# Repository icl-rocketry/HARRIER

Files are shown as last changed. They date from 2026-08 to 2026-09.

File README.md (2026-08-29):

# Project HARRIER

Solid-state particle detector for a rocket payload. Detects cosmic radiation
throughout flight and logs each hit with altitude, to build up counting
statistics post-flight.

Built in KiCad. Mixed-signal board: the detector board reads two independent
silicon-diode detector channels and logs events. 

## How it works 

A cosmic particle hits a reverse-biased photodiode and dumps a few femtocoulombs
of charge. A charge-sensitive amplifier turns that into a ~7 mV pulse, a
comparator checks it against a tunable threshold and the output signal is processed
by a seperate Pickle Rick board.

## Repository layout

The KiCad project has five schematic sheets:
Using the ICLR Board Template

| Sheet | Contents |
|---|---|
| Root | status LEDs, connectors, test points |
| Power Board | Three isolated rails off a ~7.4V battery: +25V bias, +5V analogue, +3.3V digital |
| Detector Board | The signal chain: diodes, charge amps, comparators (2 channels) |

## specs

- **Enclosure:** Circa 90 x 90 x 100 mm (TBD), light-tight detector housing
- **Power:** ~1.5 W from a ~7.4V battery (cell TBC)
- **Detector:** 2x BPW34 photodiodes, biased at +50V
- **Front-end:** ADA4817-1 charge amp, TLV3201 comparator, per channel
- **MCU:** ESP32-S3

## Status

Work in progress. Schematic of the detector front-end is nearly
complete; layout, bring-up, and firmware still to come.

**Outstanding before layout:**
- Confirm comparator edge polarity on the bench (rising vs falling) before
  writing interrupt firmware
- Clear all ERC

## Firmware

Firmware is set up for PlatformIO. Clone the repo and open in PlatformIO to
build and flash.

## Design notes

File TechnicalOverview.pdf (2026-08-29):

## HARRIER – High Altitude Radiation Rate Ionisation Experiment Recorder

HARRIER is an experiment that is part of the New Horizons’ Payload for launch at EUROC 2026. It is a photodiode-based radiation detector that aims to measure the change in radiation rate at different altitudes. We expect the rate to increase with altitude as cosmic rays are less attenuated by the atmosphere at higher altitudes.
It consists of 2 separate boards; a detector board that contains the photodiode and outputs a digital signal and a power board that provides 25V and 5V voltages, as well as containing the on/off switch. They are stored along with their own separate battery in a 5mm thick casing that blocks alpha radiation.

## The experiment

HARRIER outputs a ‘high’ signal when a particle is detected. By monitoring the output channel, we store the timestamps where detection events occurred. This can allow us to synchronise the events with altitude readings on the Pickle-Rick’s altimeter, producing a list of events and the altitudes they occur

## The detector

A photodiode is utilised to detect incoming radiation. When particles collide with the silicon surface of the diode, ionisation of donor atoms can occur, which results in additional free electrons being increased. This manifests as a small introduction of charge (on order of several femtocoulombs) and therefore current across the diode. To increase the sensitivity of the photodiode, a 25V reverse bias is applied this photodiode. Then we convert this change in charge to a voltage output signal using a charge-sensitive preamplifier (CSP), which produces an output proportional to the integrated charge over its sampling time. This means small fluctuations in current can be detected once converted into a voltage output. During detection events, a voltage of ~7mV is expected to be produced. The CSP requires a 5V input.
This output is then fed into a comparator which will output a ‘high’ signal (5V) if a voltage threshold is exceeded during its sampling window. We set the voltage threshold with a voltage divider with a variable resistor. Otherwise, a ‘low’ signal of about 0V is outputted. We use this as an approximation of counts per second by counting how many times a high signal is outputted.
A voltage divider is used to reduce comparator output to 3.3V so it can be directly connected to a GPIO pin on the Pickle-Rick board, which will store the count rate data on an SD card.

Inputs required:

- +25V power rail for photodiode
- +5V power rail for comparator and CSP Outputs:
- +3.3V digital output

Design considerations
We can also distinguish cosmic rays from EM radiation by their energy levels. Massive particles generally have far higher energies than photons from EM radiation. Therefore, by setting the threshold on the comparator above a certain level we can ignore low energy counts.
An issue with the detection of cosmic rays is that they are very fast (near light speed) so will not stay long inside the photodiode. By applying a 25V reverse bias voltage we can greatly increase the response time and sensitivity, allowing detection of these fast particles.

## Power board

The secondary board simply provides power for the main detector board. We must transform the battery power input into the correct voltages for the detector, which are 5V for the comparator and 25V for the amplifier.
The 25V input is provided by a buck boost from 7.4V to 27.5V, followed by an LDO regulator that reduces the voltage to 25V. This ensures a stable output signal as battery voltage is not consistent. For the 5V rail, we use another regulator to reduce the 7.4V input to 5V.
To turn the detector on/off, a MOSFET switch is used to switch the boost and 5V LDO on and off by disconnecting them from the battery input. This takes a 3.3V GPIO input from either the Flint and Steel board or the main Pickle Rick board. In turn, this deactivates the detector board. The power board should activate when the rest of the payload module turns on.
Inputs:
- ~7.4V battery input
- ~ 3.3V digital on/off input Outputs:

- +25V rail
- +5V rail

Design considerations:
We decided to separate the detector board from the power board for 2 main reasons.
1. Horizontal spacing requirements in the payload module- the detector should roughly point upwards for the highest count rate of cosmic radiation, but this would make a combined board to wide to fit into the casing. By separating the boards, we can mount the detector horizontally and the power board vertically, ensuring we had enough space.
2. Testing and reliability - we could independently test the detector board and if necessary, replace it if it was not working or malfunctioned. This reduces the risks of failure as if either board fails, it can be replaced separately.

## Casing

The Harrier module is designed to be self-contained. It is connected to the Pickle Rick with the data output from the comparator and the on/off switch labels. It has its own separate battery within its case. We use a separate battery to ensure that power draw is more stable, so the input voltage and current is more consistent.
The casing consists of two 3D printed parts that slot together to form a closed box. Raised screws are used to hold the boards in place.
A key issue with photodiode detectors is that electromagnetic radiation will also be detected by the diode. We can avoid this by using a casing that blocks visible light from falling on the diode. Microwaves and radio waves may penetrate the casing, but they have far lower photon energies so are unlikely to cause any ionisation.

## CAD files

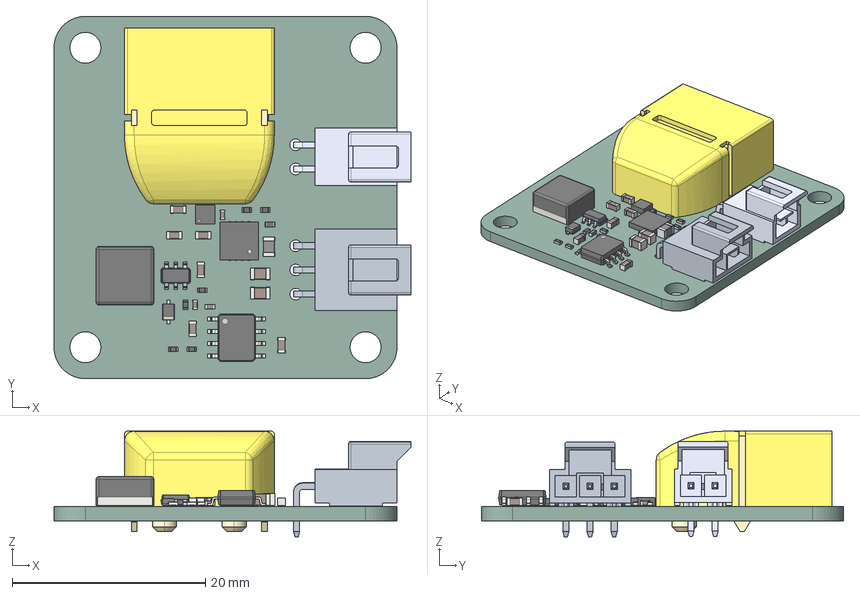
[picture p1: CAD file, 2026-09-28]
raven-main/Detector-Power-Board/power-board.step
36.9 x 37.5 x 10.9 mm
C_0603_1608Metric x 6
C_0402_1005Metric x 3
R_0402_1005Metric x 7
WSON_6_1EP_2x2mm_P065mm_EP1x16mm
Texas_RSA_VQFN-16-1EP_4x4mm_P0.65mm_EP2.7x2.7mm
XT60PW MALE
C_0805_2012Metric x 2
SOIC-8-1EP_3.9x4.9mm_P1.27mm_EP2.41x3.81mm
L_Cenker_CKCS6028
L_0805_2012Metric
D_SOD_323F
TSOP-6_1.65x3.05mm_P0.95mm
detector-power_PCB

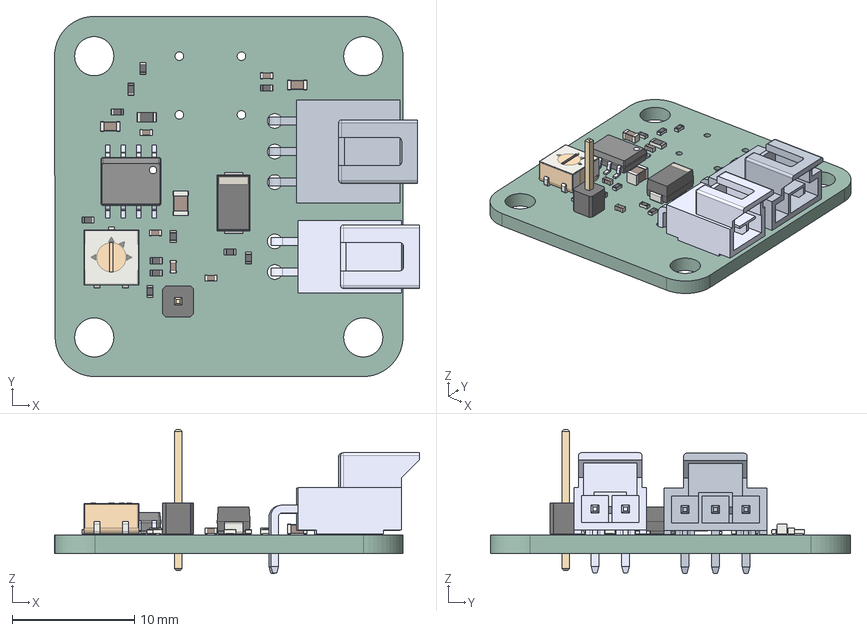
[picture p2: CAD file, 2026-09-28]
raven-main/Detector-Proto-Board/Detector-Proto-Board.step
29.9 x 29.5 x 11.8 mm
R_0402_1005Metric x 11
STS8DN3LLH5
C_0402_1005Metric x 5
Potentiometer_Bourns_3314J_Vertical
PinHeader_1x01_P254mm_Vertical
C_0603_1608Metric x 2
R_0603_1608Metric
C_0805_2012Metric
D_SMA
Detector-Proto-Board-unsaved-export-pvpNuH_PCB

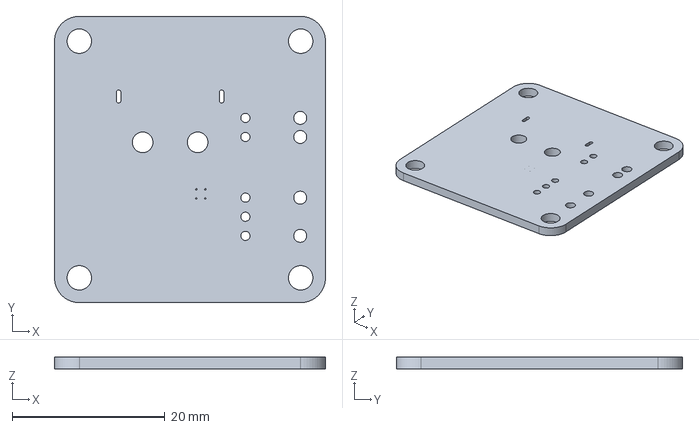
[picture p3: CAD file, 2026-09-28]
raven-main/Detector-Power-Board/test-board2.step
35.5 x 37.5 x 1.51 mm

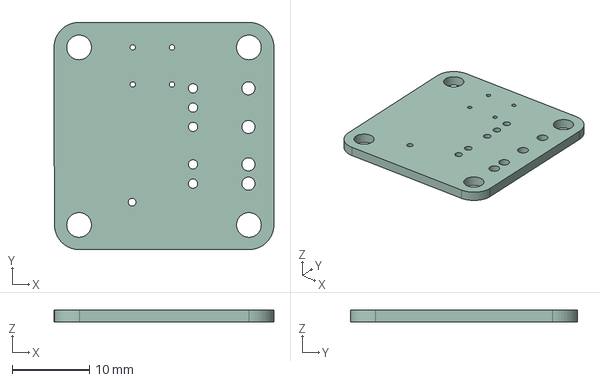
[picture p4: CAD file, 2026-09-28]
raven-main/Detector-Proto-Board/test-board.step
28.5 x 29.5 x 1.51 mm

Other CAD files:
raven-main/Detector-Proto-Board/proto-board.step

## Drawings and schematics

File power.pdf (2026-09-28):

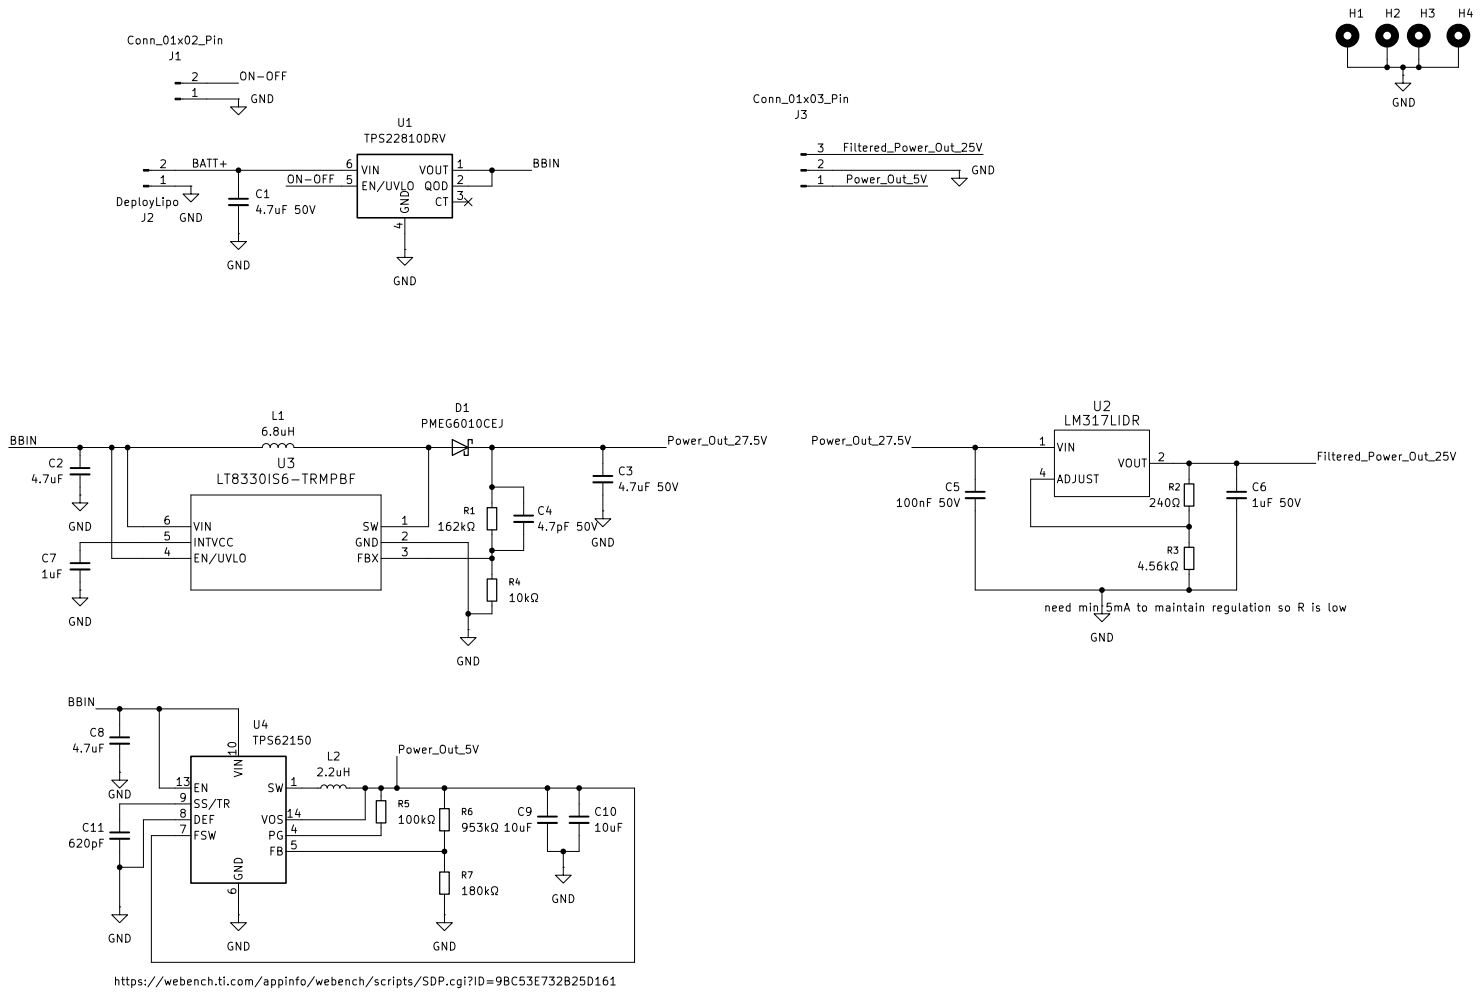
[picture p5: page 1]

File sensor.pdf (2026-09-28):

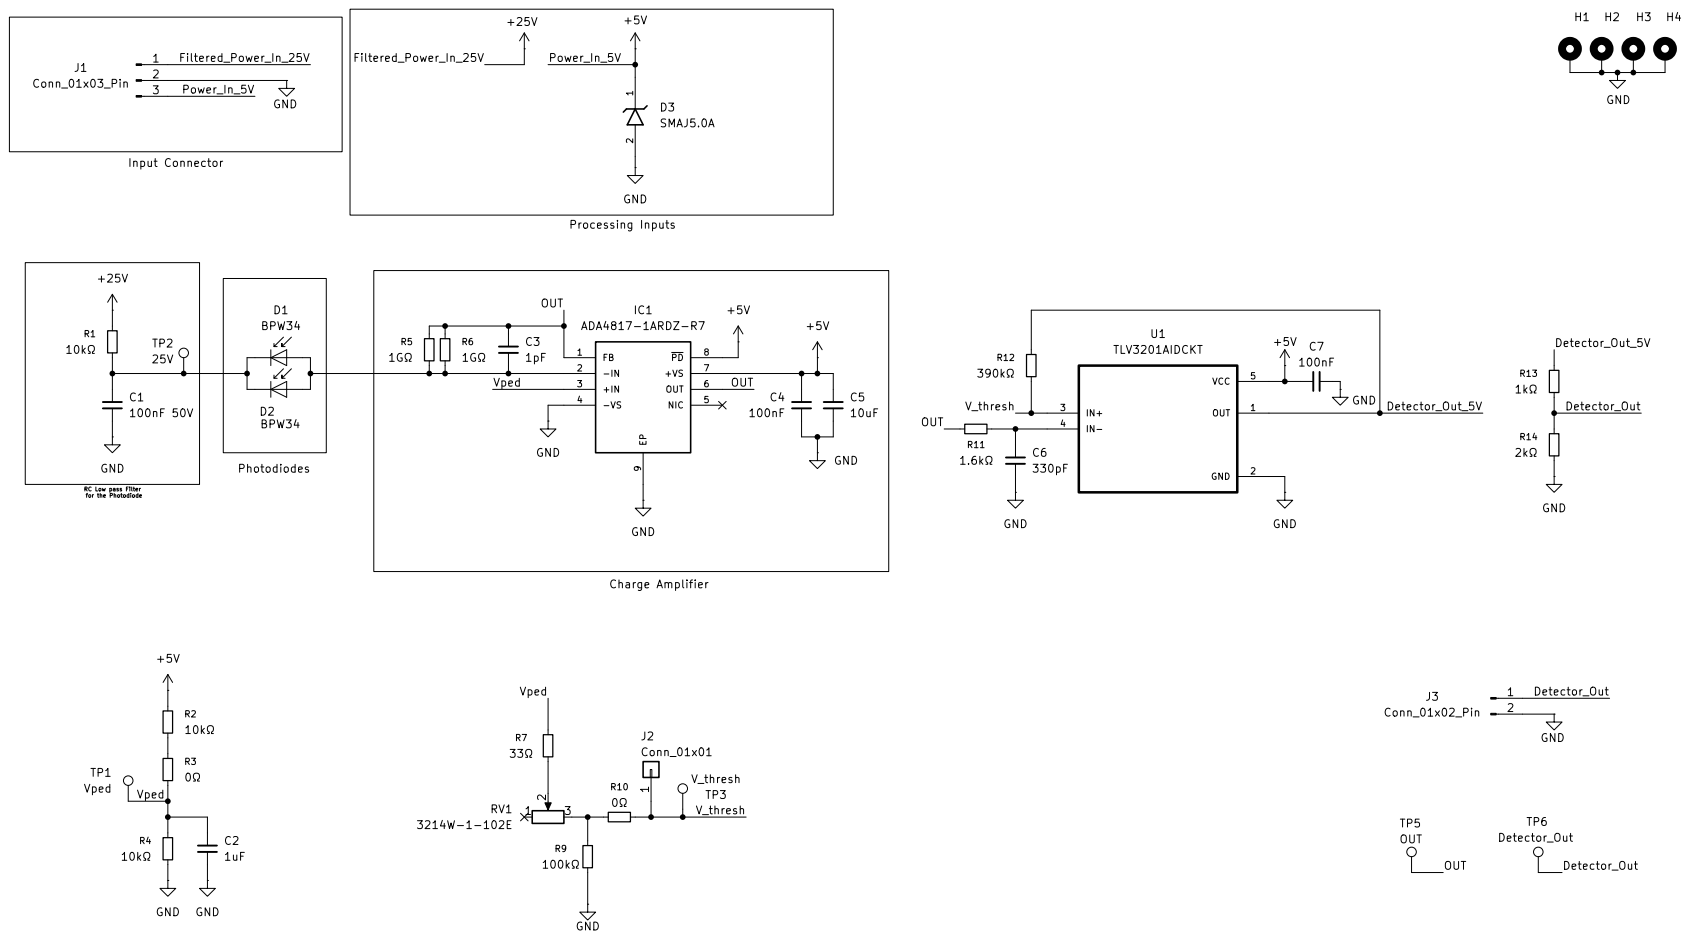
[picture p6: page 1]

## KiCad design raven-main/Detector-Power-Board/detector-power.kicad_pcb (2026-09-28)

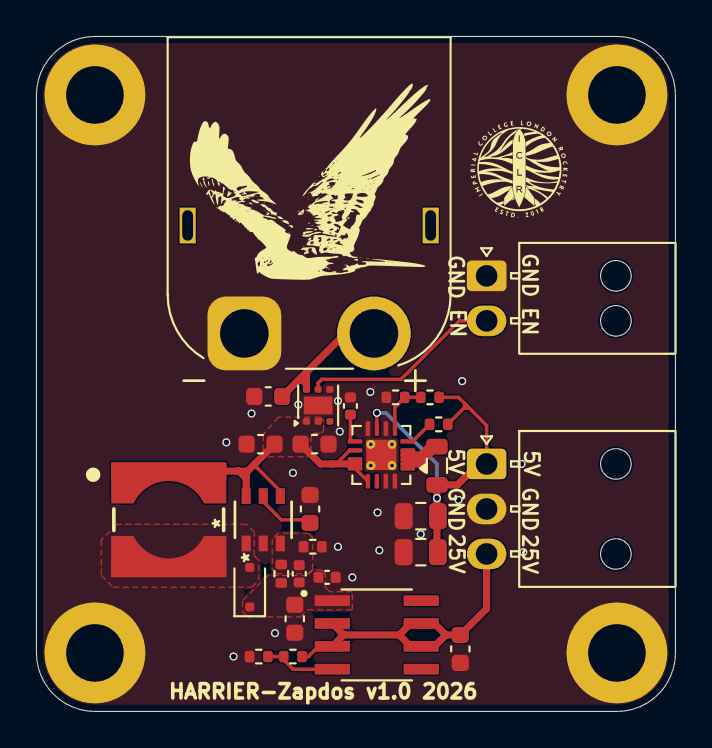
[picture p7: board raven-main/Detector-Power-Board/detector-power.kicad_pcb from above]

Board: 2 copper layers, 35.5 x 37.5 mm, 32 parts (0 on the bottom side), 15 nets.

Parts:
C1, C3: 4.7uF 50V; C_0603_1608Metric
C2, C8: 4.7uF; C_0603_1608Metric
C4: 4.7pF 50V; C_0402_1005Metric
C5: 100nF 50V; C_0402_1005Metric
C6: 1uF 50V; C_0603_1608Metric
C7: 1uF; C_0603_1608Metric
C9, C10: 10uF; C_0805_2012Metric
C11: 620pF; C_0402_1005Metric
D1: PMEG6010CEJ; D_SOD-323F
H1, H2, H3, H4: MountingHole_Pad; MountingHole_3.2mm_M3_DIN965_Pad
J1: Conn_01x02_Pin; Molex_Nano-Fit_105313-xx02_1x02_P2.50mm_Horizontal
J2: DeployLipo; AMASS_XT60PW-M_1x02_P7.20mm_Horizontal
J3: Conn_01x03_Pin; Molex_Nano-Fit_105313-xx03_1x03_P2.50mm_Horizontal
L1: 6.8uH; WE-HEPC_6030
L2: 2.2uH; L_0805_2012Metric
R1: 162kΩ; R_0402_1005Metric
R2: 240Ω; R_0402_1005Metric
R3: 4.56kΩ; R_0402_1005Metric
R4: 10kΩ; R_0402_1005Metric
R5: 100kΩ; R_0402_1005Metric
R6: 953kΩ; R_0402_1005Metric
R7: 180kΩ; R_0402_1005Metric
U1: TPS22810DRV; WSON-6-1EP_2x2mm_P0.65mm_EP1x1.6mm
U2: LM317LIDR; SOIC127P599X175-8N
U3: LT8330IS6-TRMPBF; IC6_LT8330IS6-TRMPBF_ADI
U4: TPS62150; VQFN-16-1EP_3x3mm_P0.5mm_EP1.68x1.68mm_ThermalVias

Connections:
/BATT+: C1.1, J2.2, U1.6 (VIN)
/BBIN: C2.1, C8.1, L1.1, U1.1 (VOUT), U1.2 (QOD), U3.4 (EN/UVLO), U3.6 (VIN), U4.10 (VIN), U4.11 (VIN), U4.12 (VIN), U4.13 (EN)
/Filtered_Power_Out_25V: C6.1, J3.3, R2.1, U2.2 (VOUT), U2.3 (VOUT), U2.6 (VOUT), U2.7 (VOUT)
/ON-OFF: J1.2, U1.5 (EN/UVLO)
/Power_Out_5V: C9.1, C10.1, J3.1, L2.2, R5.1, R6.1, U4.7 (FSW), U4.14 (VOS)
/Power_Out_27.5V: C3.1, C4.1, C5.1, D1.1 (K), R1.1, U2.1 (VIN)
GND: C1.2, C2.2, C3.2, C5.2, C6.2, C7.2, C8.2, C9.2, C10.2, C11.2, H1.1 (1_1), H2.1 (1_1), H3.1 (1_1), H4.1 (1_1), J1.1, J2.1, J3.2, R3.2, R4.2, R7.2, U1.4 (GND), U1.7 (GND), U3.2 (GND), U4.6 (GND), U4.8 (DEF), U4.15 (GND), U4.16 (GND), U4.17 (GND)
unnamed: D1.2 (A), L1.2, U3.1 (SW)
unnamed: L2.1, U4.1 (SW), U4.2 (SW), U4.3 (SW)
unnamed: R2.2, R3.1, U2.4 (ADJUST)
unnamed: C4.2, R1.2, R4.1, U3.3 (FBX)
unnamed: C7.1, U3.5 (INTVCC)
unnamed: R6.2, R7.1, U4.5 (FB)
unnamed: R5.2, U4.4 (PG)
unnamed: C11.1, U4.9 (SS/TR)

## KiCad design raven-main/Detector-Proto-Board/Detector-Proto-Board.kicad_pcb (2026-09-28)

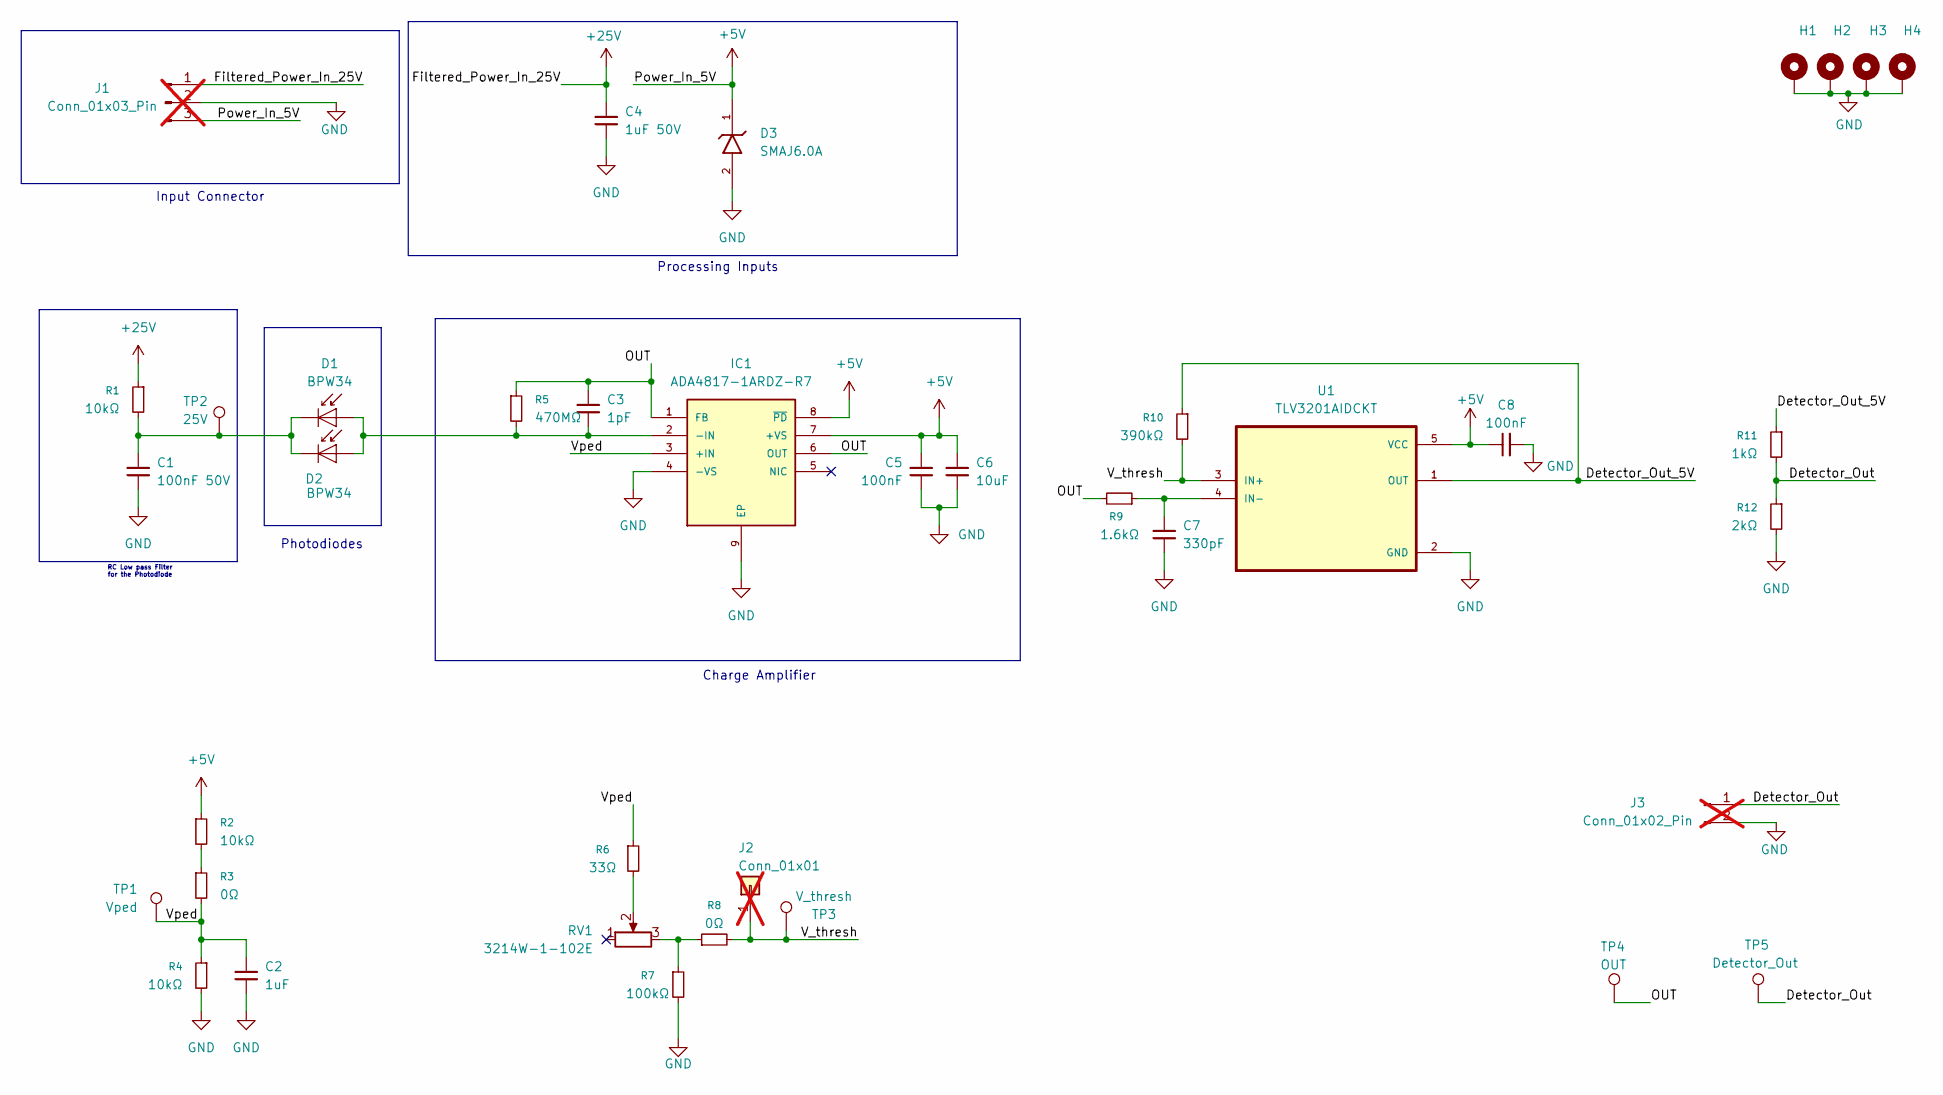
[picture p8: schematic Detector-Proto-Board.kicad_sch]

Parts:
C1: 100nF 50V; C_0402_1005Metric
C2: 1uF; C_0603_1608Metric
C3: 1pF; C_0402_1005Metric
C4: 1uF 50V; C_0603_1608Metric
C5, C8: 100nF; C_0402_1005Metric
C6: 10uF; C_0805_2012Metric
C7: 330pF; C_0402_1005Metric
D1, D2: BPW34; Osram_DIL2_4.3x4.65mm_P5.08mm
D3: SMAJ6.0A; D_SMA; MOUSER_PART_NUMBER 576-SMAJ5.0A
H1, H2, H3, H4: MountingHole_Pad; MountingHole_3.2mm_M3_DIN965_Pad
IC1: ADA4817-1ARDZ-R7; SOIC127P600X175-9N; Mouser_Part_Number 584-ADA4817-1ARDZ-R7
J1: Conn_01x03_Pin; Molex_Nano-Fit_105313-xx03_1x03_P2.50mm_Horizontal; not fitted
J2: Conn_01x01; PinHeader_1x01_P2.54mm_Vertical; not fitted
J3: Conn_01x02_Pin; Molex_Nano-Fit_105313-xx02_1x02_P2.50mm_Horizontal; not fitted
R1, R2, R4: 10kΩ; R_0402_1005Metric
R3, R8: 0Ω; R_0402_1005Metric
R5: 470MΩ; R_0603_1608Metric
R6: 33Ω; R_0402_1005Metric
R7: 100kΩ; R_0402_1005Metric
R9: 1.6kΩ; R_0402_1005Metric
R10: 390kΩ; R_0402_1005Metric
R11: 1kΩ; R_0402_1005Metric
R12: 2kΩ; R_0402_1005Metric
RV1: 3214W-1-102E; Potentiometer_Bourns_3214W_Vertical
TP1: Vped; TestPoint_Pad_D2.0mm
TP2: 25V; TestPoint_Pad_D2.0mm
TP3: V_thresh; TestPoint_Pad_D2.0mm
TP4: OUT; TestPoint_Pad_D2.0mm
TP5: Detector_Out; TestPoint_Pad_D2.0mm
U1: TLV3201AIDCKT; SOT65P210X110-5N

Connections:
+5V: C5.1, C6.1, C8.1, D3.1, IC1.7 (+VS), IC1.8 (~PD), J1.3, R2.1, U1.5 (VCC)
+25V: C4.1, J1.1, R1.1
/Detector_Out: J3.1, R11.2, R12.1, TP5.1 (1_1)
/Detector_Out_5V: R10.1, R11.1, U1.1 (OUT)
/OUT: C3.1, IC1.1 (FB), IC1.6 (OUT), R5.1, R9.2, TP4.1 (1_1)
/V_thresh: J2.1 (Pin_1_1), R8.2, R10.2, TP3.1 (1_1), U1.3 (IN+)
/Vped: C2.1, IC1.3 (+IN), R3.2, R4.1, R6.1, TP1.1 (1_1)
GND: C1.2, C2.2, C4.2, C5.2, C6.2, C7.2, C8.2, D3.2, H1.1 (1_1), H2.1 (1_1), H3.1 (1_1), H4.1 (1_1), IC1.4 (-VS), IC1.9 (EP), J1.2, J3.2, R4.2, R7.2, R12.2, U1.2 (GND)
unnamed: C3.2, D1.2 (A), D2.2 (A), IC1.2 (-IN), R5.2
unnamed: C1.1, D1.1 (K), D2.1 (K), R1.2, TP2.1 (1_1)
unnamed: R2.2, R3.1
unnamed: R6.2, RV1.2
unnamed: R7.1, R8.1, RV1.3
unnamed: C7.1, R9.1, U1.4 (IN-)

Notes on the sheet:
Photodiodes
Processing Inputs
RC Low pass Filter for the Photodiode
Charge Amplifier
Input Connector

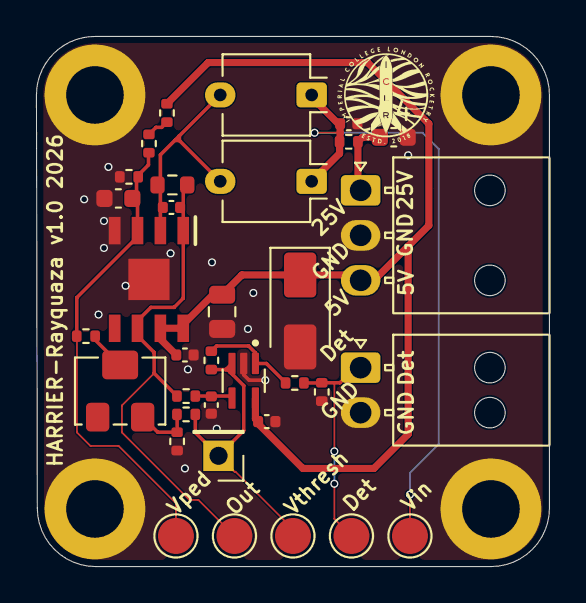
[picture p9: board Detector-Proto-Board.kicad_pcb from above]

Board: 2 copper layers, 28.5 x 29.5 mm, 38 parts (0 on the bottom side), 14 nets.

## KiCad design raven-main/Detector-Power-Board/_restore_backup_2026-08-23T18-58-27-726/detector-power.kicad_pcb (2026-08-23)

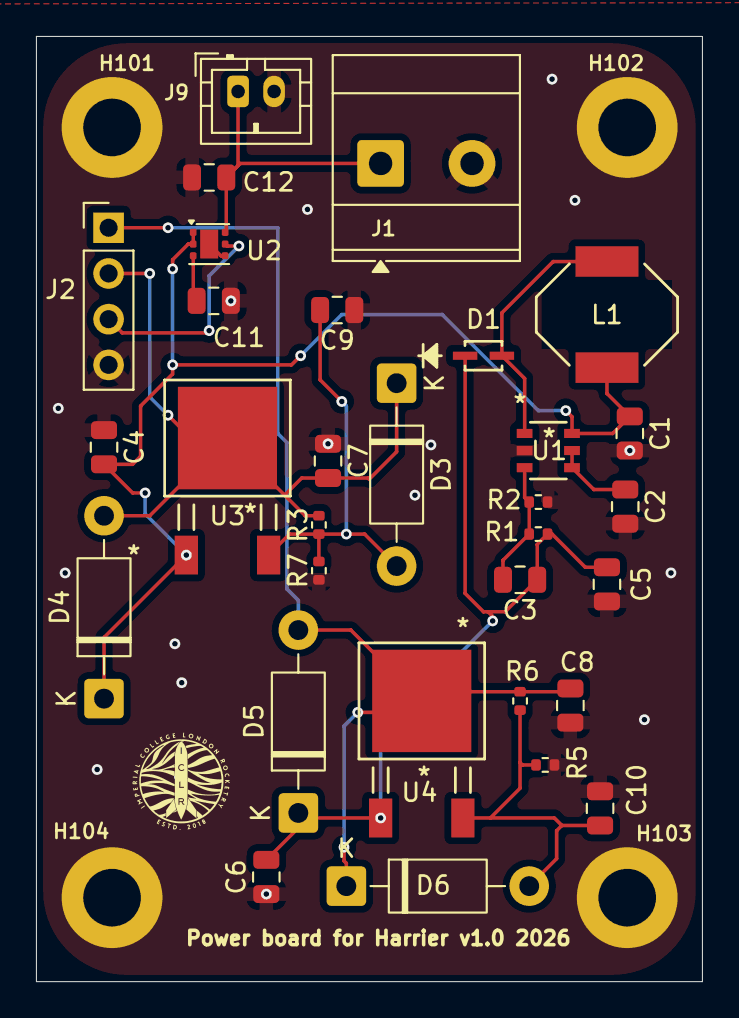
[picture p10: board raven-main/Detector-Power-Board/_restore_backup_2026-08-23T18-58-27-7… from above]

Board: 2 copper layers, 37.0 x 52.5 mm, 35 parts (0 on the bottom side), 14 nets.

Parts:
C1, C5: 4.7u; C_0805_2012Metric
C2, C7, C8, C9, C10: 1u; C_0805_2012Metric
C3: 4.7p; C_0805_2012Metric
C4, C6: 0.1u; C_0805_2012Metric
C11: 1n; C_0805_2012Metric
C12: 5u; C_0805_2012Metric
D1: D_Schottky; SOD323F_NEX
D3, D4, D5, D6: 1N4002; D_DO-41_SOD81_P10.16mm_Horizontal
H101, H102, H103, H104: MountingHole_Pad; MountingHole_3.2mm_M3_DIN965_Pad
J1: DeployLipo; TerminalBlock_Phoenix_MKDS-3-2-5.08_1x02_P5.08mm_Horizontal
J2: Conn_01x04; PinHeader_1x04_P2.54mm_Vertical
J9: UCLipo; JST_PH_B2B-PH-K_1x02_P2.00mm_Vertical
L1: 8.2u; IND_8R0NC_SUM
R1: 162k; R_0402_1005Metric
R2: 10k; R_0402_1005Metric
R3, R6: 240; R_0402_1005Metric
R5: 4.56k; R_0402_1005Metric
R7: 720; R_0402_1005Metric
U1: LT8330IS6-TRMPBF; IC6_LT8330IS6-TRMPBF_ADI
U2: TPS22810DRV; WSON-6-1EP_2x2mm_P0.65mm_EP1x1.6mm
U3, U4: LM317LCLPRE3; TD03B_TEX

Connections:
/BBIN: C1.1, C4.2, D4.1 (K), L1.1, U1.6 (VIN), U2.1 (VOUT), U2.2 (QOD), U3.1 (INPUT)
/Filtered_Power_Out_25V: C8.2, D5.2 (A), D6.1 (K), J2.1, R6.2, U4.2 (OUTPUT)
/ON-OFF: J2.3, U2.5 (EN/UVLO)
/Power_Out_5V: C7.2, D3.1 (K), D4.2 (A), J2.2, R3.2, U3.2 (OUTPUT)
/Power_Out_27.5V: C3.1, C5.1, C6.2, D1.1 (K), D5.1 (K), R1.1, U4.1 (INPUT)
GND: C1.2, C2.2, C4.1, C5.2, C6.1, C7.1, C8.1, C9.1, C10.1, C11.2, C12.2, H101.1 (1_1), H102.1 (1_1), H103.1 (1_1), H104.1 (1_1), J1.2, J2.4, J9.2, R2.2, R5.1, R7.1, U1.2 (GND)
unnamed: D1.2 (A), L1.2, U1.1 (SW)
unnamed: C9.2, D3.2 (A), R3.1, R7.2, U3.3 (ADJUSTMENT)
unnamed: C10.2, D6.2 (A), R5.2, R6.1, U4.3 (ADJUSTMENT)
unnamed: C12.1, J1.1, J9.1, U2.6 (VIN)
unnamed: C2.1, U1.4 (EN/UVLO), U1.5 (INTVCC)
unnamed: C3.2, R1.2, R2.1, U1.3 (FBX)
unnamed: C11.1, U2.3 (CT)
unnamed: U2.4 (GND), U2.7 (GND)

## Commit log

2026-08-23 Replaced LDO with correct one
    [Detector-Proto-Board.kicad_pcb, detector-power.kicad_pcb, detector-power.kicad_sch]
2026-08-23 More efficient routing
    [detector-power.kicad_pcb]
2026-08-29 Optional rerouting for lower impedence
    [Detector-Proto-Board.kicad_pcb, detector (proto-board) latest.step, power_board_latest.step]
2026-09-17 power board done
    [Detector-Proto-Board.kicad_pcb, Detector-Proto-Board.kicad_sch, detector-power.kicad_pcb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]
2026-09-17 updated detector - need to order
    [Detector-Proto-Board.kicad_pcb, Detector-Proto-Board.kicad_sch, detector-power.kicad_pcb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]
2026-09-28 new docs/3d files
    [CorrectedProtoBoard.step, Detector-Proto-Board.kicad_pcb, Detector-Proto-Board.kicad_sch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]
